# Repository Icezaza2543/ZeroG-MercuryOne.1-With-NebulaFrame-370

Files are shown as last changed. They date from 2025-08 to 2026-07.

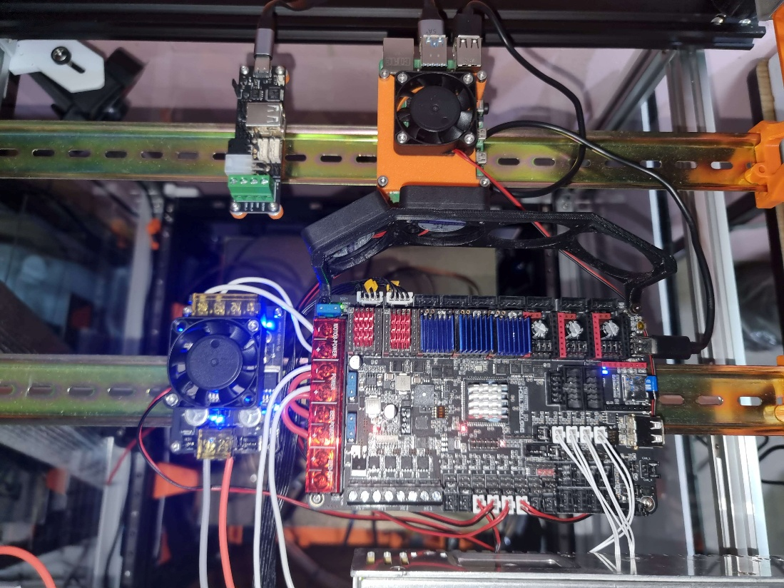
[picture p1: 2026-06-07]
Media/image16.png

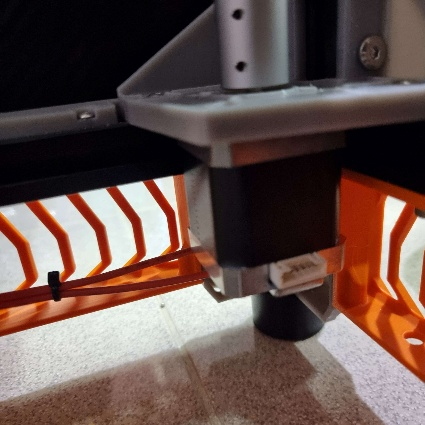
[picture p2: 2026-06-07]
Media/image20.png

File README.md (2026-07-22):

<div align="center">

# 🚀 ZeroG MercuryOne.1 x NebulaFrame 370 x Hydra Bed

### *High-Speed CoreXY 3D Printer Conversion Platform*

**Handmade with ❤️ by Icezaza**








</div>

---

## 📖 1. Project Overview

This project is a comprehensive **CoreXY conversion** platform for **Ender 5 / Ender 5 Pro / Ender 5 Plus** 3D printers. It elevates print speeds beyond **600 mm/s** with accelerations up to **20,000 mm/s²**, designed specifically for reliable high-temperature engineering filament printing (**ABS, ASA, PC**).

### 🔑 Core Pillars

1. **⚡ ZeroG Mercury One.1 (CoreXY Kinematics):**  
   Converts stock single-axis movement into a lightweight, high-acceleration **CoreXY** gantry system for fast, precise motion.
2. **🏗️ NebulaFrame 370 (High-Temp Enclosure):**  
   Sealed acrylic/polycarbonate enclosure frame maintaining ambient chamber temperatures to prevent thermal warping in ABS, ASA, and PC prints.
3. **🔥 Hydra Bed System (3-Point Independent Z-Tilt):**  
   Kinematic **3-Point Z-Tilt** bed mechanism driven by 3 independent Z stepper motors for 100% automated bed tramming and leveling.
4. **🧠 Advanced Klipper Ecosystem:**  
   Powered by a **BigTreeTech Octopus Pro (STM32H723)** controller, **BTT EBB36 CANbus** toolhead MCU, and **Cartographer / Beacon 3D Probe** with pre-configured **KAMP (Klipper Adaptive Meshing & Purging)** and **ShakeTune**.

---

## 📊 2. Technical Specifications

| Specification / Parameter | Details & Hardware Model |
| :--- | :--- |
| **Print Kinematics** | CoreXY Kinematics (ZeroG Mercury One.1) |
| **Max Speed & Acceleration** | **Speed:** >600 mm/s \| **Acceleration:** 20,000 mm/s² |
| **Main Controller** | BigTreeTech Octopus Pro (STM32H723, 32-bit @ 550MHz) |
| **Toolhead MCU** | BigTreeTech EBB36 v1.2 (CANbus Interface) |
| **X/Y Motor Drivers** | 2x TMC5160 Pro (SPI Mode @ 1.97A Run Current) |
| **Z Motor Drivers** | 3x TMC2209 (UART Mode @ 1.45A Run Current) |
| **X/Y Motors** | LDO-42STH48-2804AH-R (High-Torque 0.9° Steppers) |
| **Z Motors** | 3x NEMA17 Steppers (Hydra 3-Point Z-Tilt Drive) |
| **Extruder** | Orbiter 2.0 Dual-Drive Direct Extruder |
| **Bed Surface Scanner** | Cartographer 3D / Beacon 3D Surface Scanner |
| **Part Cooling** | 5015 High-Static Pressure Blower Fan (24V) |
| **Firmware & Software** | Klipper + Moonraker + Mainsail + KAMP + KlipperScreen |

---

## 🏗️ 3. System Architecture & Workflows

```mermaid
graph TD
    A[Ender 5 Platform] -->|Conversion| B(ZeroG Mercury One.1 CoreXY)
    B --> C{Core Components}
    
    C -->|Enclosure| D[NebulaFrame 370 Enclosure]
    C -->|Bed Kinematics| E[Hydra 3-Point Z-Tilt Bed]
    C -->|Toolhead Engine| F[Orbiter 2.0 + EBB36 CANbus]
    C -->|Surface Probe| G[Cartographer / Beacon 3D Probe]

    E -->|Auto Leveling| H[Z_TILT_ADJUST Automated Leveling]
    F & G -->|Control Hub| I[Klipper Firmware + BTT Octopus Pro]
    I -->|Configs| J[Config/printer.cfg]
```

---

## 📂 4. Repository Structure

```mermaid
mindmap
  root((ZeroG-MercuryOne.1))
    BOM.md
      (Hardware Specifications)
    Config
      [printer.cfg & macros.cfg]
      [KAMP & KlipperScreen]
      [crowsnest & timelapse]
    File_To_Print
      (HydraBed STLs)
      (MercuryXY STLs)
      (Skirt STLs)
      (ToolsHead STLs)
    Manuals
      [Assembly_Guide.md]
      [PDF Instructions]
    Archives
      [CAD ZIP Packages]
    Media
      [Build Media & Test Print Video]
```

### 📋 Folder Responsibilities

* 🔩 **[`BOM.md`](BOM.md):** Complete Bill of Materials specifying fasteners, linear rails, belts, motors, and electronics.
* 💾 **[`Config/`](Config/):** Production Klipper configuration files (`printer.cfg`, `macros.cfg`, `KAMP_Settings.cfg`, `KlipperScreen.conf`).
* 🖨️ **[`File_To_Print/`](File_To_Print/):** Categorized 3D printable STL files (`HydraBed/`, `MercuryXY/`, `Skirt/`, `ToolsHead/`).
* 📖 **[`Manuals/`](Manuals/):** Markdown assembly guide ([`Assembly_Guide.md`](Manuals/Assembly_Guide.md)) and official PDF manuals.
* 📦 **[`Archives/`](Archives/):** Compressed archives containing original CAD models.
* 📷 **[`Media/`](Media/):** Video demonstrations and project media assets.

---

## 🛠️ 5. Quick Start & Assembly Guide

### 1️⃣ Step 1: Review Hardware Requirements
Inspect the complete Bill of Materials for screws, heat-set inserts, MGN12H linear rails, and motor specifications in 🔩 **[BOM.md](BOM.md)**.

### 2️⃣ Step 2: Print Required Parts
Slice STL files from 🖨️ **[File_To_Print/](File_To_Print/)** with recommended settings:
* **Recommended Material:** ABS or ASA (High thermal resistance)
* **Wall Loops / Perimeters:** 4–5 walls
* **Top / Bottom Layers:** 5 layers
* **Infill:** 40% (Gyroid or Grid pattern)

### 3️⃣ Step 3: Assemble Mechanical Gantry & Frame
Follow step-by-step assembly instructions in 📖 **[Manuals/Assembly_Guide.md](Manuals/Assembly_Guide.md)**.

### 4️⃣ Step 4: Install Klipper Configuration
Copy configuration files from 💾 **[Config/](Config/)** into your Klipper environment (`printer_data/config/`).

### 5️⃣ Step 5: Execute Machine Calibration
Run Klipper calibration macros via console:

```gcode
# 1. Automatic 3-Point Z-Tilt Leveling
Z_TILT_ADJUST

# 2. Bed Mesh Calibration
BED_MESH_CALIBRATE

# 3. Hotend & Heated Bed PID Tuning
PID_CALIBRATE HEATER=extruder TARGET=240
PID_CALIBRATE HEATER=heater_bed TARGET=100

# 4. Resonance Testing & Input Shaper Calibration
SHAKETUNE
```

---

## ❓ 6. Troubleshooting & FAQs

<details>
<summary><b>❓ Why is ABS or ASA required for printed components?</b></summary>
<br>
Inside the NebulaFrame 370 enclosure, ambient chamber temperatures reach 50–60°C. Parts printed in PLA or PETG will soften and deform under heat, causing gantry misalignment and loose belt tension.
</details>

<details>
<summary><b>❓ What causes Z-Tilt leveling errors or motor binding?</b></summary>
<br>
Verify that motor pin definitions and coordinates for <code>stepper_z</code>, <code>stepper_z1</code>, and <code>stepper_z2</code> in <code>printer.cfg</code> match the physical lead screw positions on your machine.
</details>

<details>
<summary><b>❓ What printing speeds can be reliably achieved?</b></summary>
<br>
While TMC5160 drivers and LDO high-torque steppers support travel speeds over 600 mm/s, high-quality production printing is recommended between 250–450 mm/s for optimal surface finish on ABS/ASA.
</details>

---

## 🤝 7. Credits & Acknowledgements

Special thanks to the open-source community:
* 🚀 **[ZeroG Design Community](https://github.com/ZeroGDesign):** Creators of the ZeroG Mercury One.1 CoreXY platform.
* ⚙️ **[Klipper Project](https://www.klipper3d.org/):** High-performance 3D printer firmware.
* 🇹🇭 **Thai Maker Community (Icezaza):** Design customization and project documentation.

---

<div align="center">

**📄 License:** [CC BY-NC-SA 4.0](https://creativecommons.org/licenses/by-nc-sa/4.0/) & [CC0 1.0 Universal](LICENSE)  

*⭐ If you find this project helpful, please give it a star on GitHub!*

</div>

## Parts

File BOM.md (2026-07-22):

# 🔩 Bill of Materials (BOM) - ZeroG MercuryOne.1 x NebulaFrame 370 x Hydra Bed

**Project:** ZeroG Mercury One.1 CoreXY Conversion + NebulaFrame 370 + Hydra Bed  
**Author:** Thai Maker (Icezaza)  
**Target Printer Platform:** Ender 5 / Ender 5 Pro / Ender 5 Plus  

---

## 📑 1. Core Electronics & Hardware Specs

| Category | Component | Specification / Model | Qty | Notes |
| :--- | :--- | :--- | :---: | :--- |
| **Main Controller** | Mainboard | BigTreeTech Octopus Pro (STM32H723) | 1 | 32-bit controller, high-speed USB/CAN |
| **Toolhead MCU** | Toolhead CAN Board | BTT EBB36 v1.1 / v1.2 (CANbus) | 1 | Mounts directly on Orbiter 2.0 |
| **Host System** | Single Board Computer | Raspberry Pi 3/4 / CB1 | 1 | Runs Klipper, Mainsail, Moonraker |
| **X/Y Steppers** | High-Speed Motors | LDO-42STH48-2804AH-R (2.8A, 0.9°) | 2 | CoreXY Motion (Driven by TMC5160 @ 1.97A) |
| **Z Steppers** | Hydra Bed Motors | NEMA17 (42DND887C-20D18 1.7A) | 3 | 3-Point Independent Z-Tilt Kinematic Bed |
| **X/Y Drivers** | Stepper Drivers | BTT TMC5160 Pro / TMC5160 (SPI) | 2 | High current & high speed motion |
| **Z Drivers** | Stepper Drivers | BTT TMC2209 (UART) | 3 | Quiet operation with stealthChop/spreadCycle |
| **Toolhead Extruder**| Extruder | Orbiter 2.0 Dual Drive | 1 | Lightweight direct-drive extruder |
| **Surface Probe** | 3D Bed Scanner | Cartographer 3D / Beacon 3D Probe | 1 | High-speed Eddy Current Surface Scanner |
| **Part Cooling** | Blower Fan | 5015 Dual Ball Bearing Fan (24V) | 1 | Single/Dual 5015 Duct Mount |
| **Hotend Fan** | Cooling Fan | 3010 Axial Fan (24V) | 1 | EBB36 Toolhead Cooling |
| **Resonance Test** | Accelerometer | ADXL345 (Integrated on EBB36) | 1 | Input Shaper Calibration |

---

## 🏗️ 2. Mechanical & Linear Motion (Kinematics)

| Component | Specification | Qty | Notes |
| :--- | :--- | :---: | :--- |
| **Linear Rails (X-Axis)** | MGN12H (300mm / 350mm / 450mm based on Ender model) | 1 | Heavy-duty top-rail carriage mount |
| **Linear Rails (Y-Axis)** | MGN12H | 2 | Side rail positioning |
| **Linear Rails (Z-Axis)** | MGN12H | 3 | Hydra 3-point vertical guides |
| **GT2 Belt (X/Y)** | GT2 6mm or 9mm Gates Unitta Belt | ~4.5m | CoreXY belt loop routing |
| **Pulleys (Toothed)** | 20T GT2 Pulley (5mm bore) | 2 | X/Y Stepper Motor Shafts |
| **Idlers (Smooth)** | 20T Smooth Idler (5mm bore) | 6 | Gantry corner & tensioners |
| **Idlers (Toothed)** | 20T Toothed Idler (5mm bore) | 8 | Gantry corner & tensioners |
| **Lead Screws** | T8x4 / T8x8 Lead Screw + Anti-backlash Nut | 3 | Hydra Z-Axis motor drives |

---

## 🔩 3. Fasteners & Brass Inserts (Hardware BOM)

| Fastener Type | Dimensions | Approximate Qty | Application |
| :--- | :--- | :---: | :--- |
| **Heat-Set Inserts** | M3 x 5mm x 4mm (Brass) | 60+ | All 3D Printed Parts |
| **Button Head Screws**| M3 x 6mm | 40+ | Rail mounting & brackets |
| **Button Head Screws**| M3 x 8mm | 50+ | Frame & component mounts |
| **Button Head Screws**| M3 x 12mm | 30+ | Motor mounts & joints |
| **Button Head Screws**| M3 x 16mm / 20mm | 20+ | Toolhead & fan mounts |
| **Socket Head Screws**| M4 x 10mm / 12mm | 20+ | Frame extrusions |
| **Socket Head Screws**| M5 x 10mm / 16mm | 16+ | Corner brackets & bed mounts |
| **T-Nuts** | M3 T-Nuts for 2020 Aluminum Profile | 50+ | Rail & skirt mounting |
| **T-Nuts** | M4 / M5 T-Nuts for 2020 Profile | 30+ | Heavy joint mounting |

---

## 🖼️ 4. Frame & Enclosure (NebulaFrame 370)

| Material | Description / Dimensions | Qty | Application |
| :--- | :--- | :---: | :--- |
| **Aluminum Extrusions** | 2020 T-Slot Aluminum Profile | Cut to spec | Upper frame expansion & enclosure |
| **Enclosure Panels** | Acrylic or Polycarbonate Panels (3mm - 4mm) | 5 Sheets | Top, Sides, Front Doors for ABS/PC printing |
| **Insulation / Skirt** | 3D Printed Skirts (`File_To_Print/Skirt`) | 1 Set | Bottom enclosure & electronics housing |

---

## 🖨️ 5. Recommended 3D Printing Settings for Parts

| Parameter | Value |
| :--- | :--- |
| **Material** | **ABS** or **ASA** (Polycarbonate optional for high ambient temp) |
| **Wall Loops / Perimeters** | Minimum **4 Walls** (5 recommended for stress joints) |
| **Top / Bottom Layers** | **5 Solid Layers** |
| **Infill Density** | **40%** |
| **Infill Pattern** | Gyroid, Grid, or Honeycomb |
| **Layer Height** | 0.2mm |

---

<div align="center">
  <b>For Klipper Configuration files, please refer to the <a href="Config/">Config/</a> directory.</b>
</div>

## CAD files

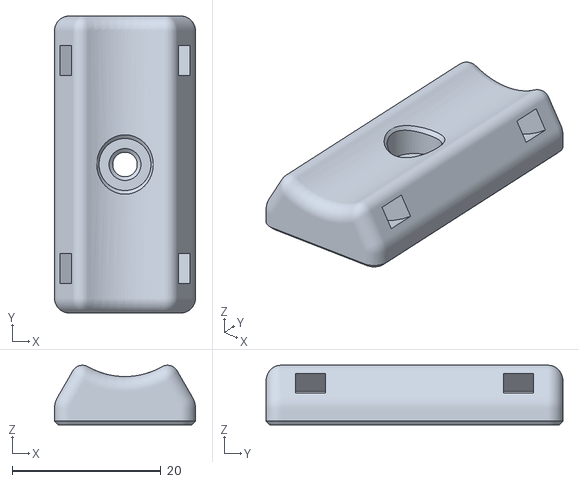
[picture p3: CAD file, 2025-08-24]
File_To_Print/HydraBed/2020_CableTie.stl
19.0 x 40.0 x 8.03

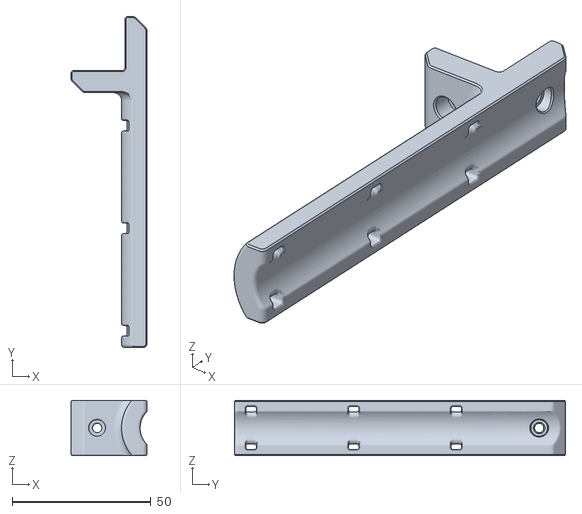
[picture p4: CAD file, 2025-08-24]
File_To_Print/MercuryXY/RearSplitloomArm_V1-1-0.stl
27.5 x 119.5 x 20.0

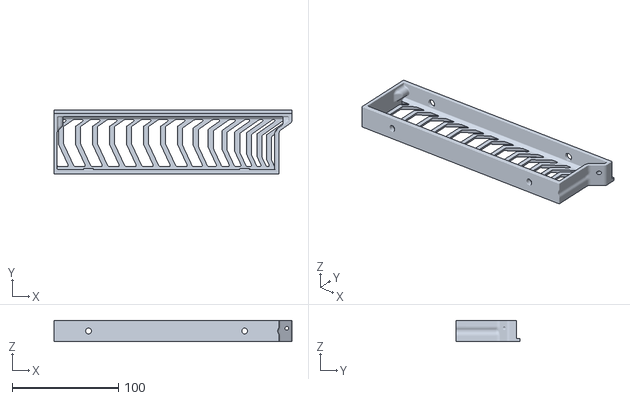
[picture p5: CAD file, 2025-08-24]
File_To_Print/Skirt/SK_480L.stl
224.1 x 60.0 x 20.0

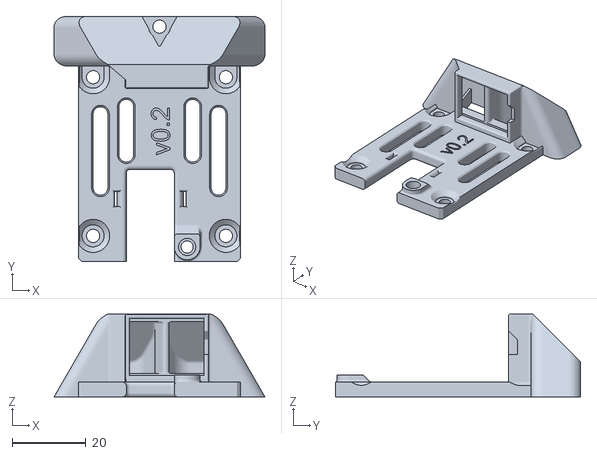
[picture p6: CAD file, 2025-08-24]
File_To_Print/ToolsHead/rear_inlet_single_5015.stl
57.2 x 66.5 x 22.5

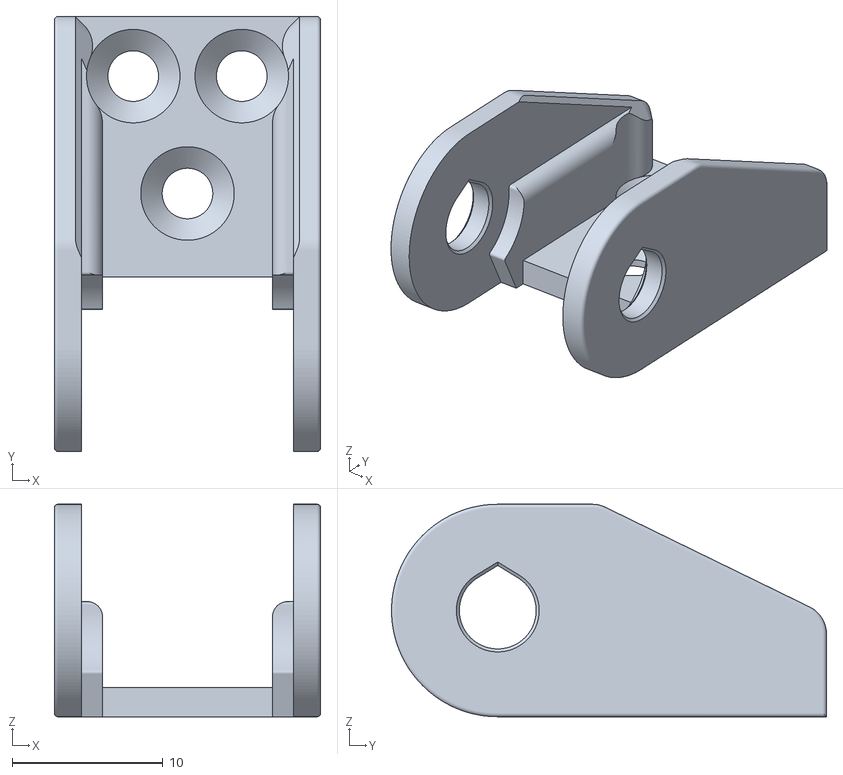
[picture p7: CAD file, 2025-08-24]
File_To_Print/HydraBed/ChainEnd.stl
17.7 x 28.9 x 14.1

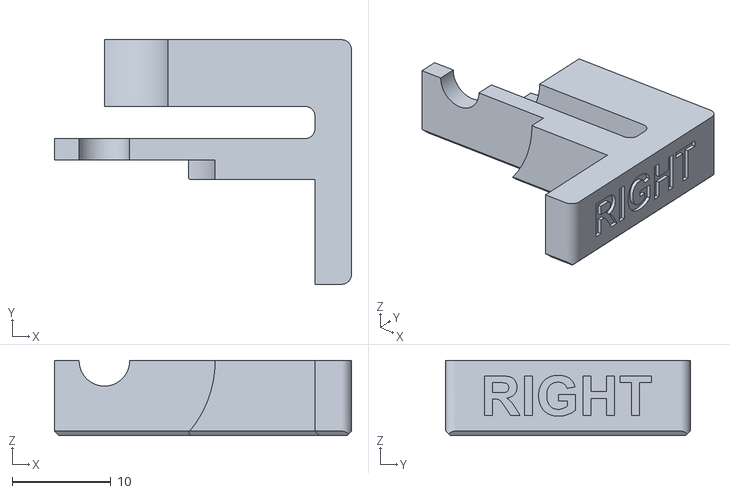
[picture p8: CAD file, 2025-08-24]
File_To_Print/MercuryXY/right_pulley_alignment_tool.stl
30.0 x 24.8 x 7.60

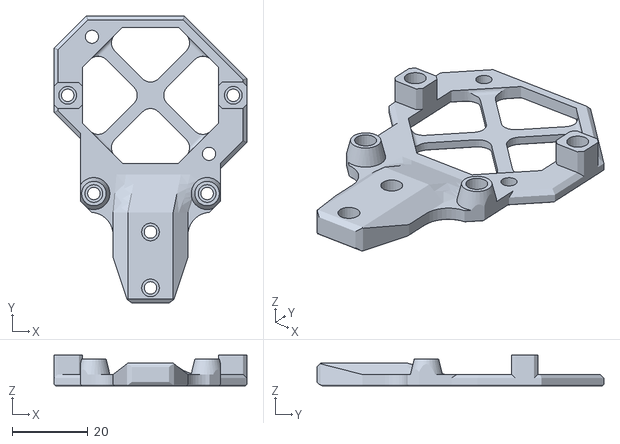
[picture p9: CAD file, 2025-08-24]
File_To_Print/ToolsHead/pcb36_mount.stl
51.0 x 76.0 x 8.10

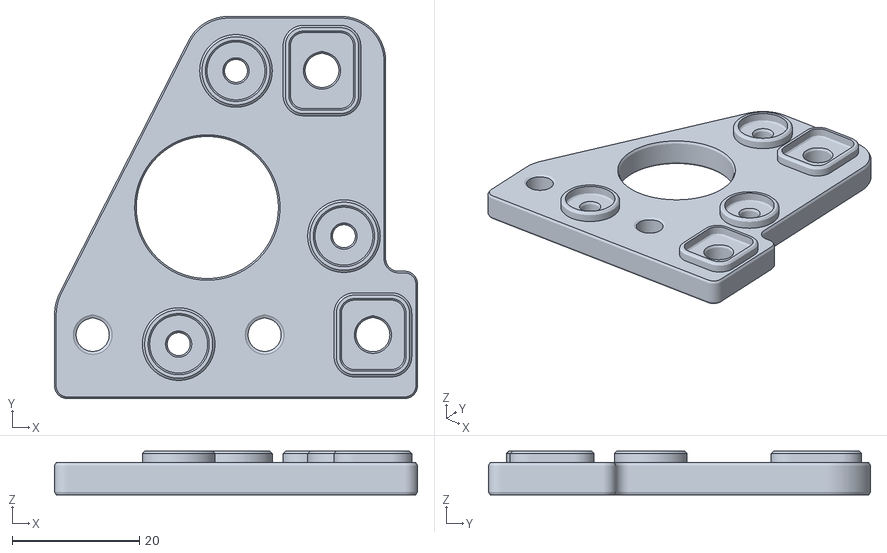
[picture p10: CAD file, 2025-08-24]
File_To_Print/MercuryXY/a_stepper_mount_top_right.stl
57.0 x 60.0 x 6.85

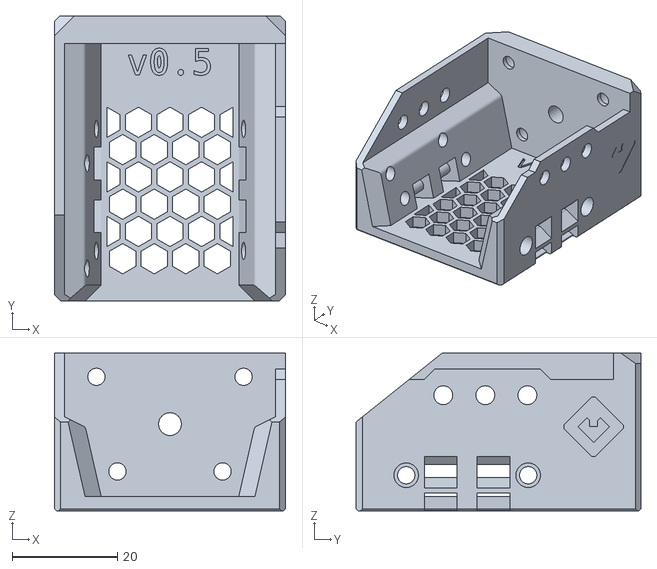
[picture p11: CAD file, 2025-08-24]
File_To_Print/ToolsHead/front_basic.stl
44.0 x 54.2 x 30.0

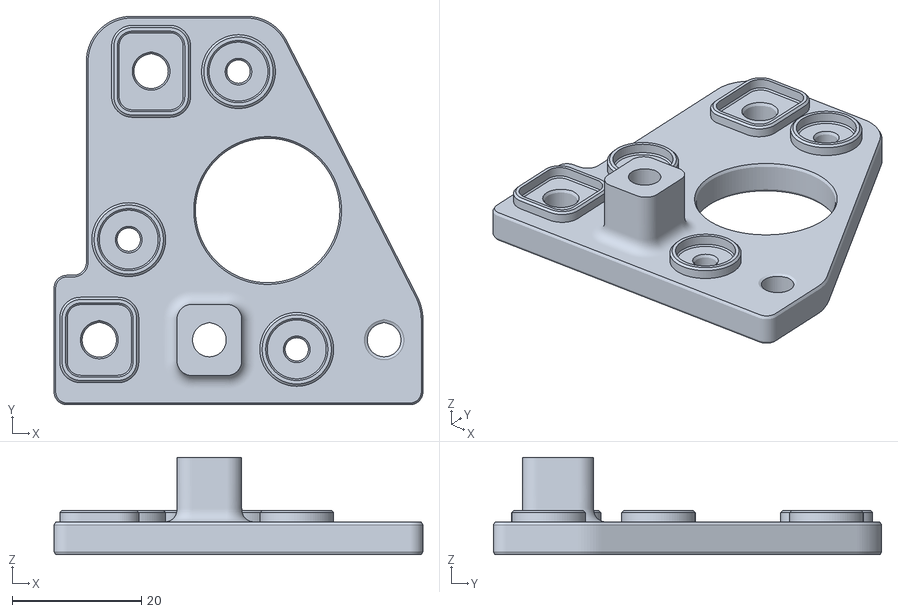
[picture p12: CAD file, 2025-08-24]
File_To_Print/MercuryXY/a_stepper_mount_top_left.stl
57.0 x 60.0 x 15.0

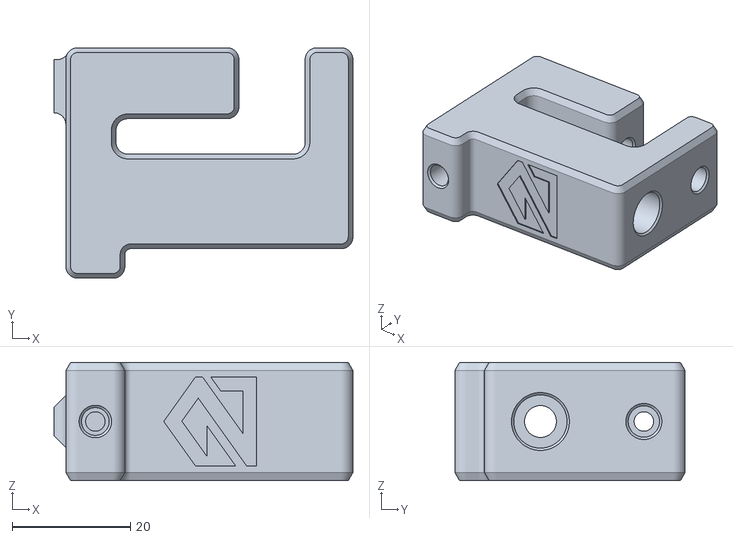
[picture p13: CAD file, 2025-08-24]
File_To_Print/MercuryXY/a_front_tower_right.stl
50.6 x 39.0 x 20.0

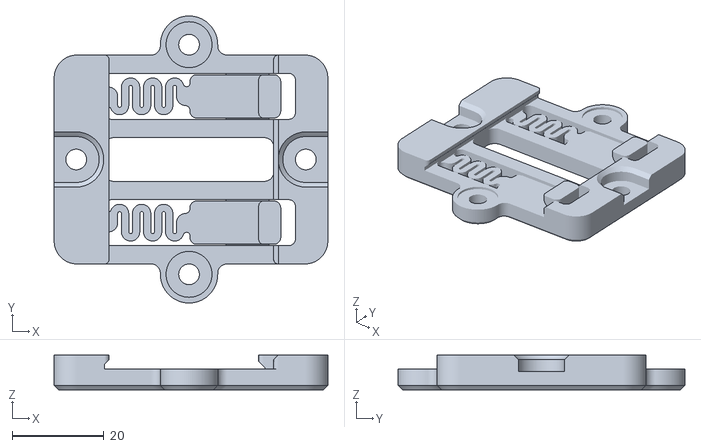
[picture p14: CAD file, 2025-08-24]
File_To_Print/ToolsHead/50mm_din_rail_mount.stl
59.6 x 62.5 x 7.60

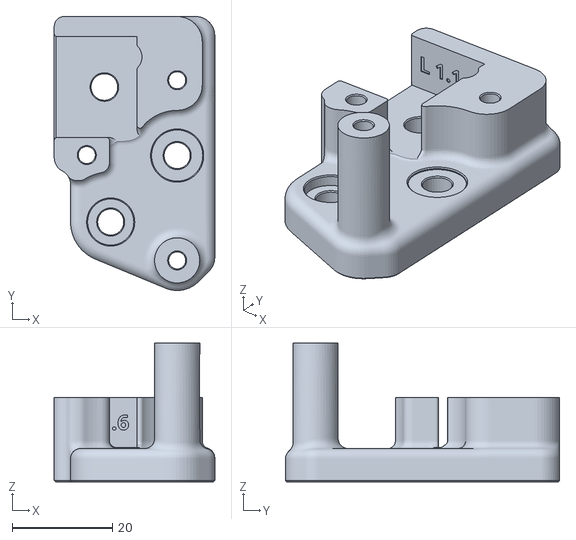
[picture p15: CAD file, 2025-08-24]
File_To_Print/MercuryXY/XJoint_left_top.stl
32.0 x 54.6 x 27.6

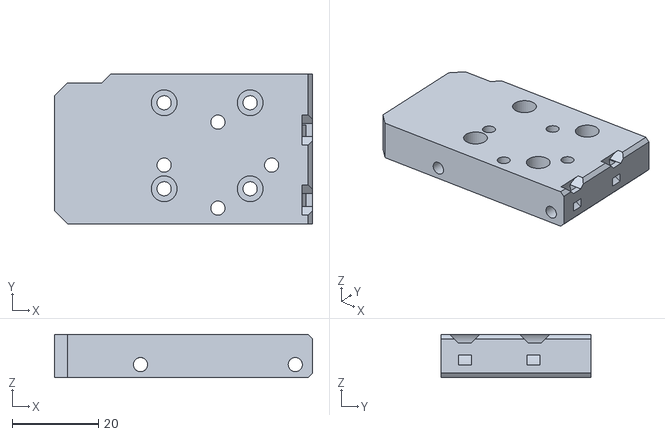
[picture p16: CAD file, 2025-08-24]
File_To_Print/ToolsHead/E34M1_Top_Limit_Right.stl
60.0 x 34.8 x 10.0

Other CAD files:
File_To_Print/Skirt/SK_480R.stl
File_To_Print/MercuryXY/plus_only_bed_raiser_1.stl
File_To_Print/ToolsHead/drive_orbiter_2_0.stl
File_To_Print/MercuryXY/XJoint_left_bottom.stl
File_To_Print/MercuryXY/XJoint_right_bottom.stl
File_To_Print/MercuryXY/XJoint_right_top.stl
File_To_Print/MercuryXY/a_FlangeSpacer_pair.stl
File_To_Print/MercuryXY/a_Xjoint_8mm_Idler_Spacers.stl
File_To_Print/MercuryXY/a_front_tower_left.stl
File_To_Print/MercuryXY/a_stepper_mount_bottom_left.stl
File_To_Print/MercuryXY/a_stepper_mount_bottom_right.stl
File_To_Print/MercuryXY/front_tension_plate_t-nut_1.stl
File_To_Print/MercuryXY/front_tension_plate_t-nut_2.stl
File_To_Print/MercuryXY/front_tower_tool.stl
File_To_Print/MercuryXY/front_tower_tool_brass.stl
File_To_Print/MercuryXY/left_pulley_alignment_tool.stl
File_To_Print/MercuryXY/plus_only_bed_raiser_2.stl
File_To_Print/MercuryXY/plus_only_bed_raiser_3.stl
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

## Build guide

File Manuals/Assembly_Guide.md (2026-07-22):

# 📘 ZeroG MercuryOne.1 + NebulaFrame 370 + Hydra Bed Assembly Guide

**Last Updated:** 2026  
**Author:** Thai Maker (Icezaza)  

This guide provides technical overview, system architecture, and assembly procedures for converting an Ender 5 series 3D printer into a high-speed CoreXY system using the ZeroG Mercury One.1 platform, NebulaFrame 370 enclosure, and Hydra 3-point kinematic Z-tilt bed leveling.

---

## 🏗️ 1. Project Overview

This project converts Ender 5 / Ender 5 Pro / Ender 5 Plus printers into high-speed CoreXY machines capable of print speeds exceeding **600 mm/s** and accelerations up to **20,000 mm/s²**, optimized for high-temperature engineering filaments like **ABS, ASA, and PC**.

**Key Core Pillars:**
1. **ZeroG Mercury One.1:** CoreXY motion system replacing single-axis X/Y movement, reducing toolhead weight for fast, precise motion.
2. **NebulaFrame 370:** Sealed enclosure frame maintaining ambient chamber temperatures to eliminate warping in high-shrinkage plastics (ABS/ASA/PC).
3. **Hydra Bed System:** 3-point kinematic Z-tilt mechanism driven by 3 independent Z stepper motors for 100% automated bed leveling.
4. **Klipper Firmware Ecosystem:** Advanced motion processing featuring Input Shaper resonance compensation, Pressure Advance, KAMP adaptive meshing, and ShakeTune diagnostics.

---

## 📂 2. Repository Structure

- **`BOM.md`**
  - Detailed Bill of Materials specifying hardware, fasteners, linear rails, belts, motors, and controller pinouts ([View BOM](../BOM.md)).
- **`Config/`**
  - Production Klipper configuration files including `printer.cfg`, `macros.cfg`, `KAMP_Settings.cfg`, `KlipperScreen.conf`, and `crowsnest.conf` ([Open Config Directory](../Config/)).
- **`Archives/`**
  - Compressed `.zip` archives containing original CAD models (`Hydra_5Plus.zip`, `Hydra_5pro.zip`, `Mercury1_1.zip`).
- **`File_To_Print/`**
  - Categorized 3D printable STL files:
    - `HydraBed/` - 3-motor Z-bed mounts & kinematic arms
    - `MercuryXY/` - CoreXY gantry, belt paths, and motor mounts
    - `Skirt/` - Electronics enclosures and lower frame skirts
    - `ToolsHead/` - Orbiter 2.0, Cartographer/Beacon 3D probe mounts, and 5015 fan ducts
- **`Manuals/`**
  - Official PDF instruction manuals and this markdown assembly guide.
- **`Media/`**
  - Test print videos (`Print_Test.mp4`) and build photography.

---

## 🛠️ 3. Pre-Assembly Guidelines

### 3D Printing Recommendations
All components in `File_To_Print/` are load-bearing structural parts operating in a heated chamber environment:
- **Recommended Materials:** ABS, ASA, or PC (PLA and PETG are not recommended due to heat deflection).
- **Perimeters / Walls:** Minimum **4 walls** (5 walls recommended for high-stress joints).
- **Infill Density:** **40%** (Gyroid, Grid, or Honeycomb).
- **Top / Bottom Solid Layers:** **5 layers**.

### Hardware Bill of Materials (BOM)
For exact quantities of M3/M4/M5 screws, brass heat-set inserts, linear rails, belts, and motor models, refer to 📖 **[BOM.md](../BOM.md)**.

---

## ⚙️ 4. Mechanical Assembly & Klipper Configuration

### 4.1 Part Preparation
1. Print all required parts from `File_To_Print/` according to the recommended print settings.
2. Install brass heat-set inserts (M3x5x4mm) into specified mounting holes using a soldering iron.
3. Cut 2020 aluminum extrusions and prepare acrylic/polycarbonate panels according to NebulaFrame 370 dimensions.

### 4.2 Mechanical Assembly
Follow the instructions in `mercury_one_1_instruction_18-02-2024.pdf` located in the `Manuals/` directory:
1. **CoreXY Gantry Installation:** Mount X and Y stepper motors to the frame and route GT2 belts in the CoreXY configuration.
2. **Hydra Bed Assembly:** Convert the stock bed platform to a 3-lead-screw kinematic mount driven by 3 independent Z steppers.
3. **Toolhead Assembly:** Assemble the Orbiter 2.0 extruder, BTT EBB36 CAN board, and probe onto the X-carriage.

### 4.3 Klipper Firmware Setup
1. Install Klipper on your host single-board computer (Raspberry Pi / CB1 running MainsailOS or FluiddPI).
2. Flash Klipper firmware to the main controller board (e.g., BigTreeTech Octopus Pro) and Toolhead MCU (EBB36).
3. Copy all files from the **[`Config/`](../Config/)** directory to your Klipper `printer_data/config/` folder:
   - **[`Config/printer.cfg`](../Config/printer.cfg)**: Configures TMC5160 X/Y drivers, TMC2209 Z steppers, Cartographer/Beacon probe, and bed mesh settings.
   - **[`Config/macros.cfg`](../Config/macros.cfg)**: Contains `PRINT_START`, `PRINT_END`, `CANCEL_PRINT`, and maintenance macros.

### 4.4 Machine Calibration
Execute calibration macros via the Klipper console:
- **Z-Tilt Leveling:** Run `Z_TILT_ADJUST` to automatically level the bed across all 3 Z steppers.
- **Bed Mesh:** Run `BED_MESH_CALIBRATE` (or rely on KAMP auto-mesh during `PRINT_START`).
- **Resonance Compensation:** Run `SHAKETUNE` or Input Shaper calibration using the ADXL345 accelerometer.
- **PID Tuning:** Run PID calibration for both hotend and heated bed (`PID_CALIBRATE`).

---

## 📌 5. Troubleshooting

- **Belt Friction / Binding:** Ensure smooth alignment of all 20T idlers and equal belt tension across A/B loops.
- **Z-Tilt Failures / Motor Binding:** Verify motor stepper assignments (`stepper_z`, `stepper_z1`, `stepper_z2`) and pivot point coordinates in `printer.cfg`.
- **Layer Shifting at High Speeds:** Check TMC5160 run currents (recommended 1.97A for LDO 0.9° steppers) and verify belt tensioning.

---

**⭐ For additional model modifications, CAD files are available in the `Archives/` folder.**

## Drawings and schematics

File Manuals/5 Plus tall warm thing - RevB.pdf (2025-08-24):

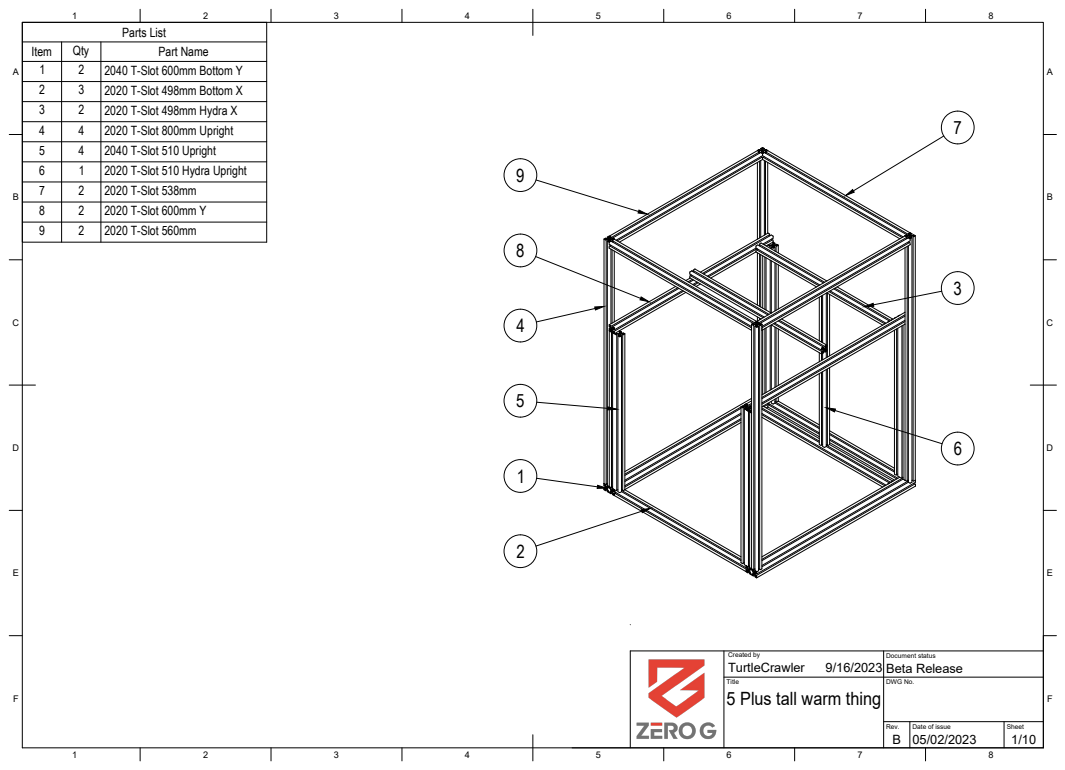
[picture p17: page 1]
Parts List

Item | Qty | Part Name
1 | 2 | 2040 T-Slot 600mm Bottom Y
2 | 3 | 2020 T-Slot 498mm Bottom X
3 | 2 | 2020 T-Slot 498mm Hydra X
4 | 4 | 2020 T-Slot 800mm Upright
5 | 4 | 2040 T-Slot 510 Upright
6 | 1 | 2020 T-Slot 510 Hydra Upright
7 | 2 | 2020 T-Slot 538mm
8 | 2 | 2020 T-Slot 600mm Y
9 | 2 | 2020 T-Slot 560mm

Created by TurtleCrawler 9/16/2023 | Document status Beta Release

Title 5 Plus tall warm thing | DWG No.

Rev. B | Date of issue 05/02/2023 | Sheet

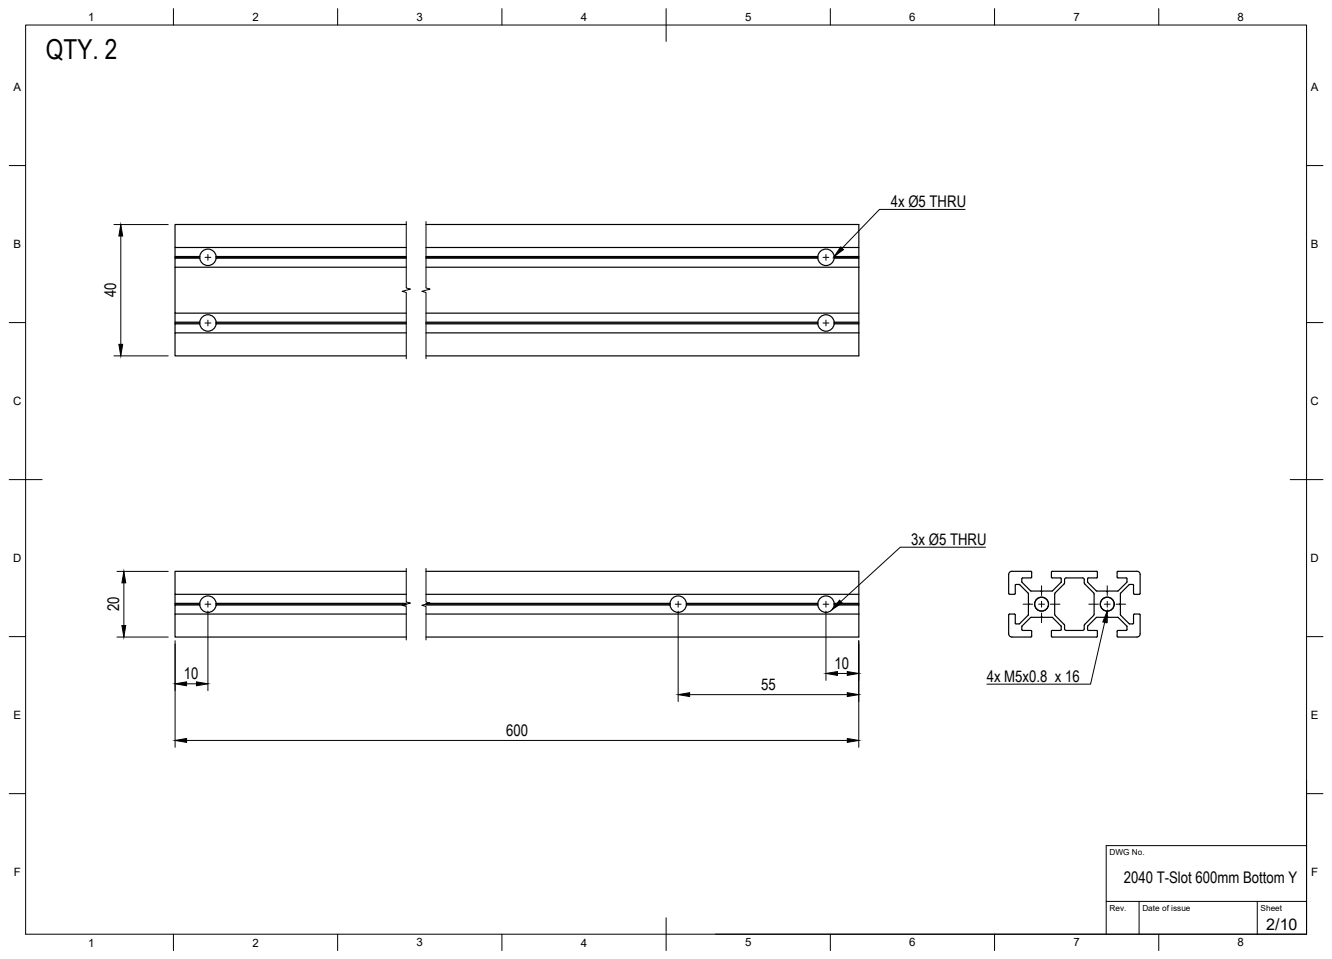
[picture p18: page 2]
DWG No. 2040 T-Slot 600mm Bottom Y; QTY. 2; 4x Ø5 THRU; 3x Ø5 THRU

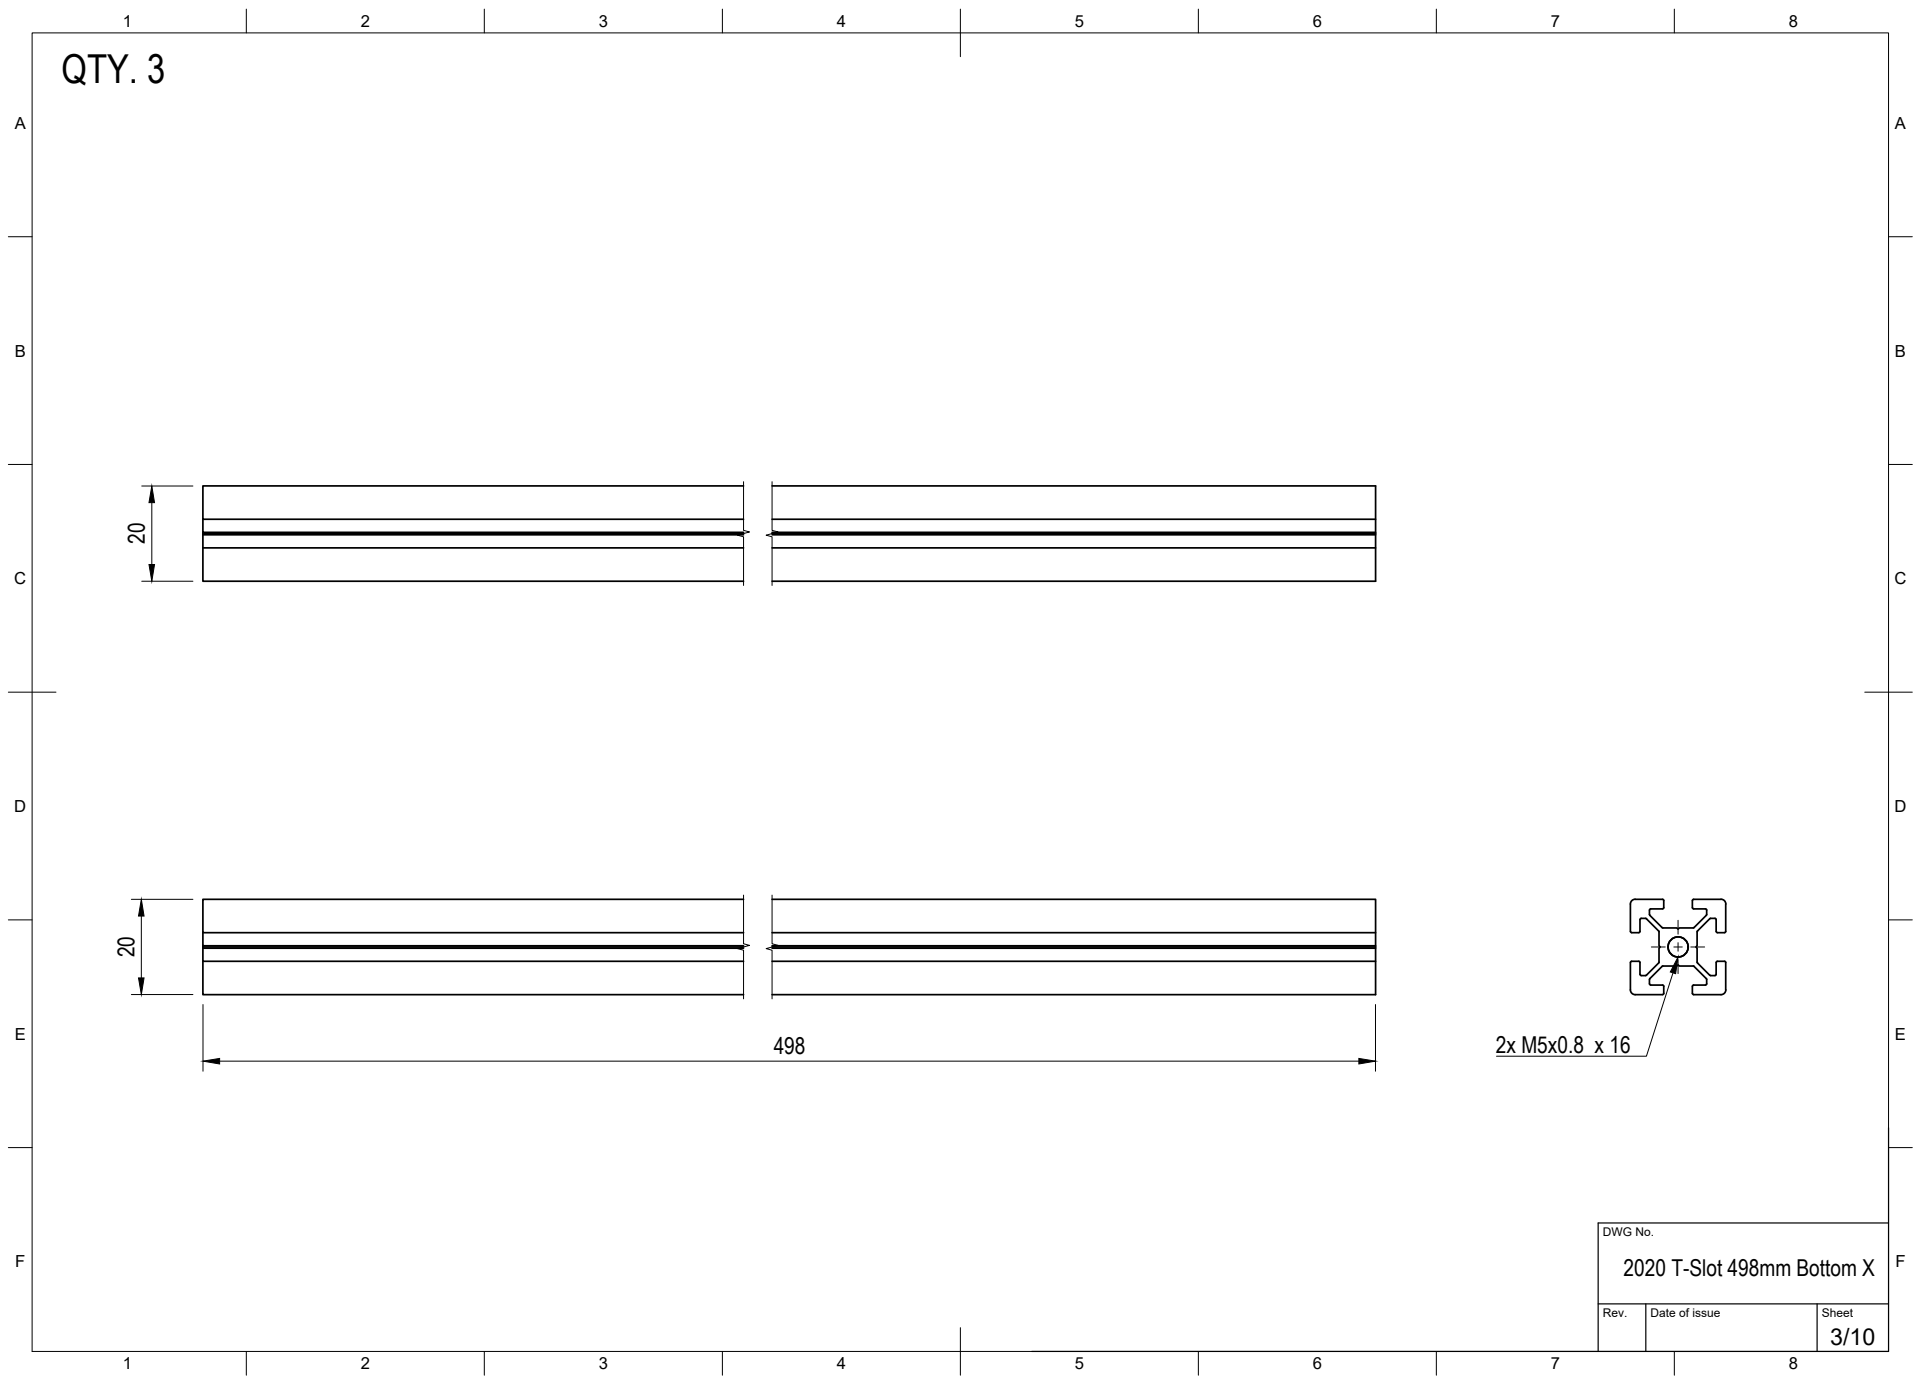
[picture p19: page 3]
DWG No. 2020 T-Slot 498mm Bottom X

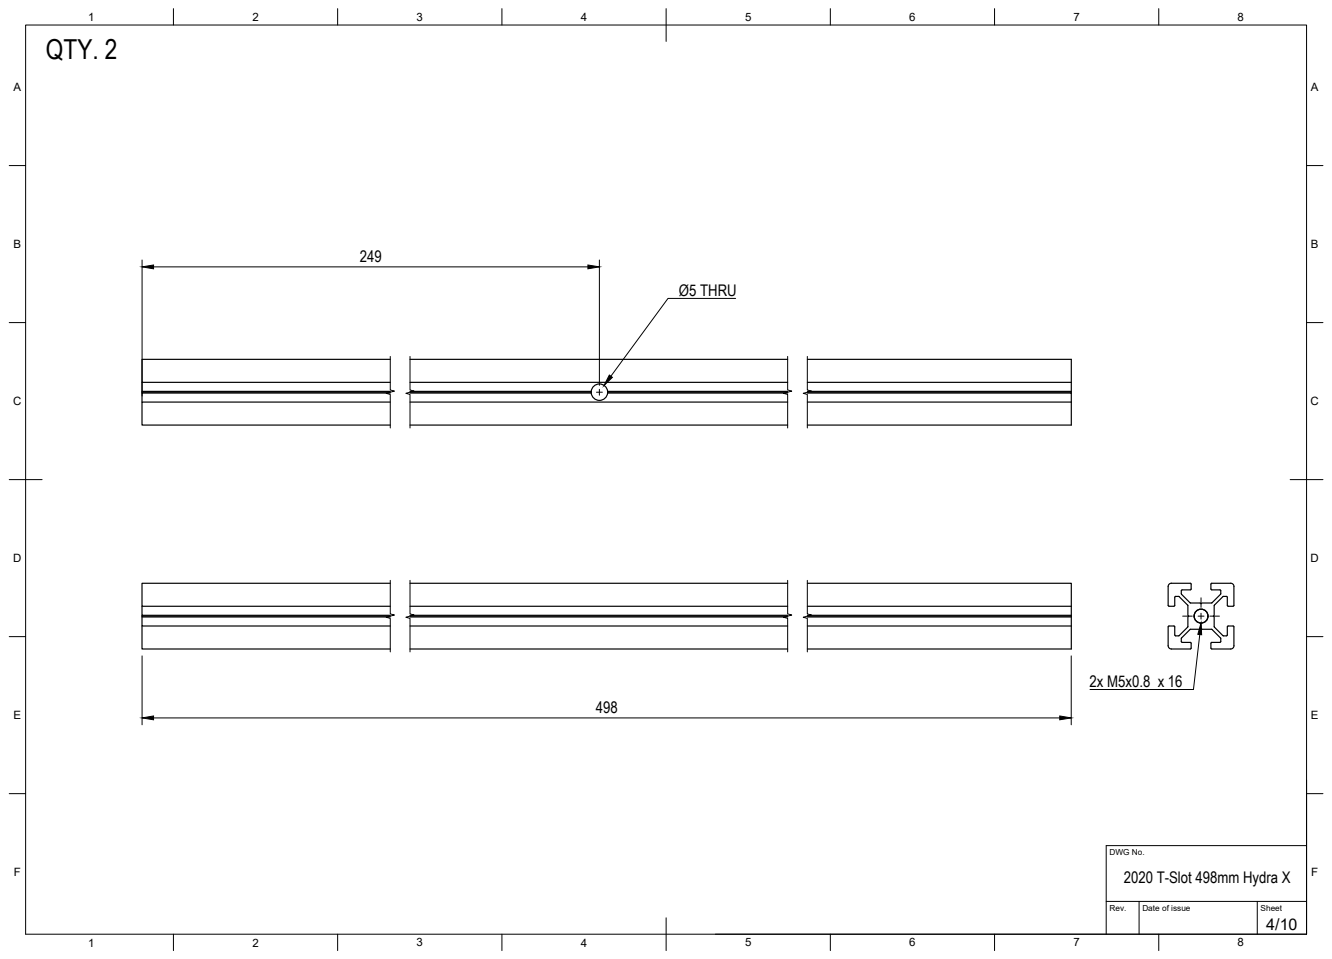
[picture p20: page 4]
DWG No. 2020 T-Slot 498mm Hydra X; Ø5 THRU

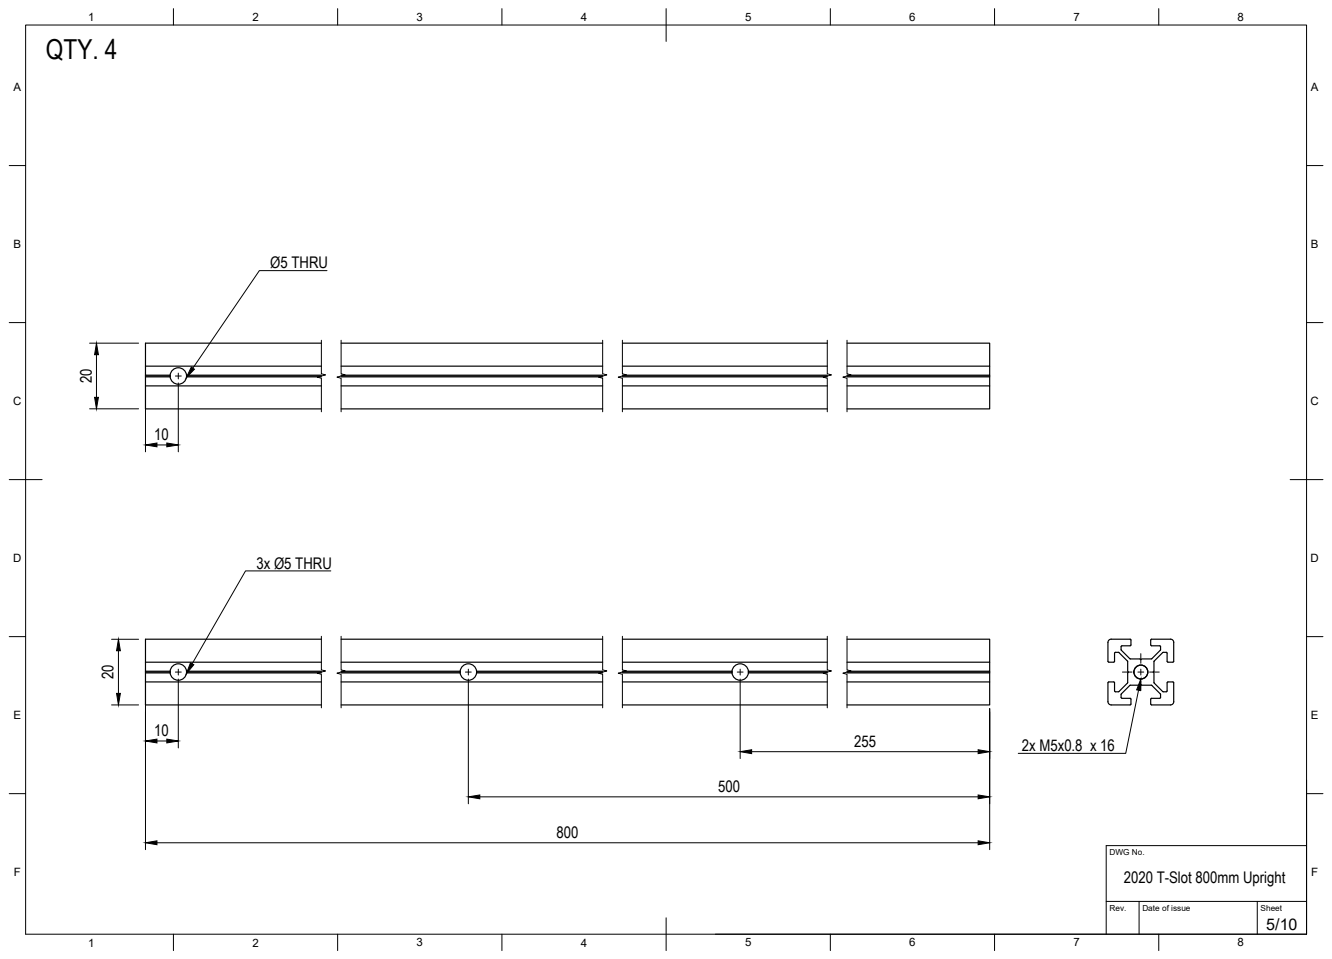
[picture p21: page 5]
DWG No. 2020 T-Slot 800mm Upright; Ø5 THRU; 3x Ø5 THRU

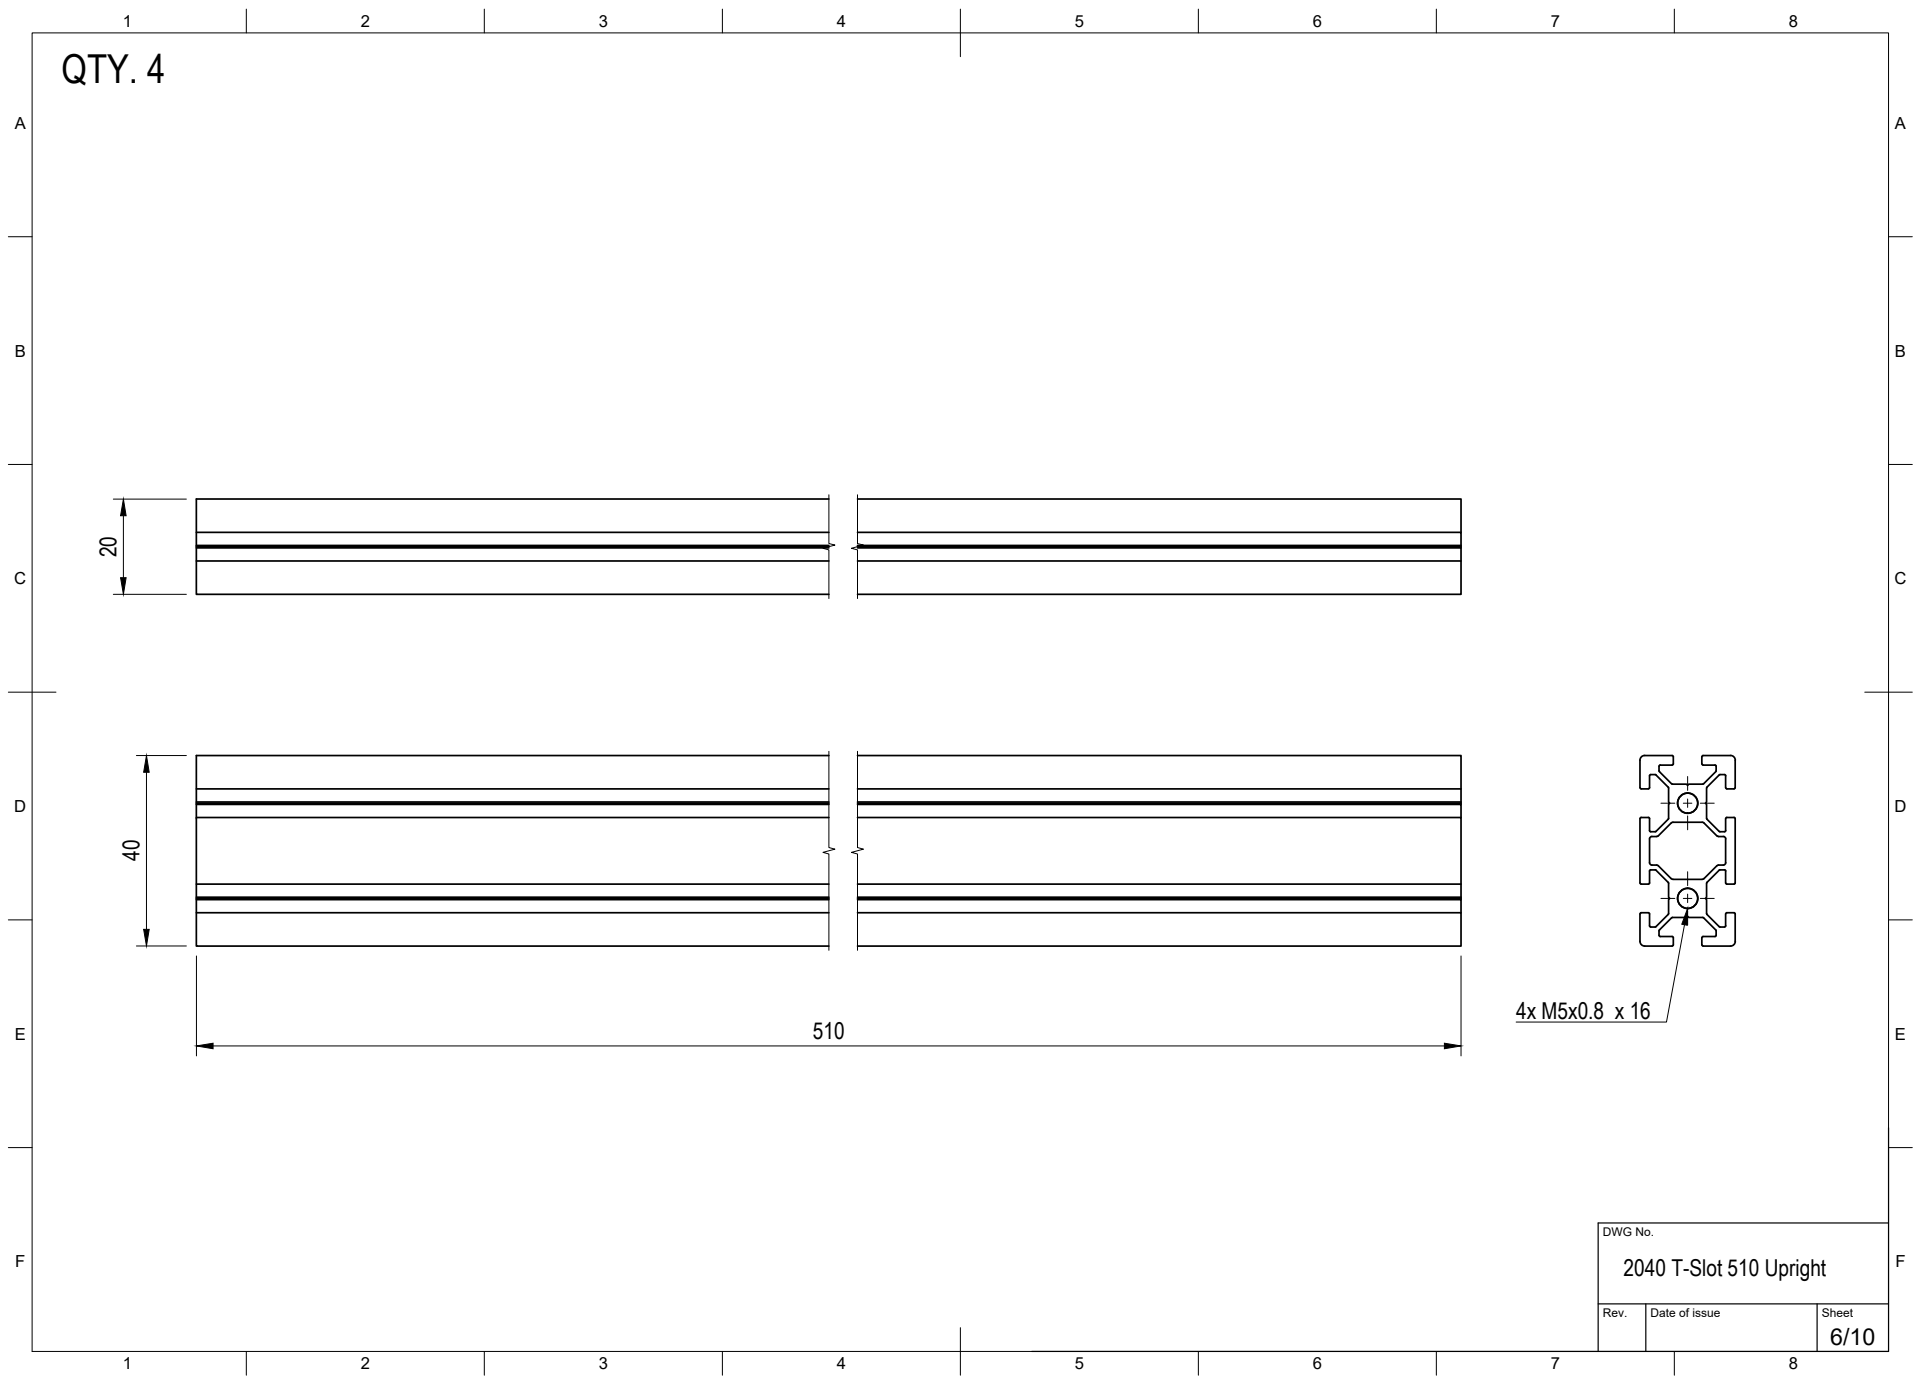
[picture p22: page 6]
DWG No. 2040 T-Slot 510 Upright

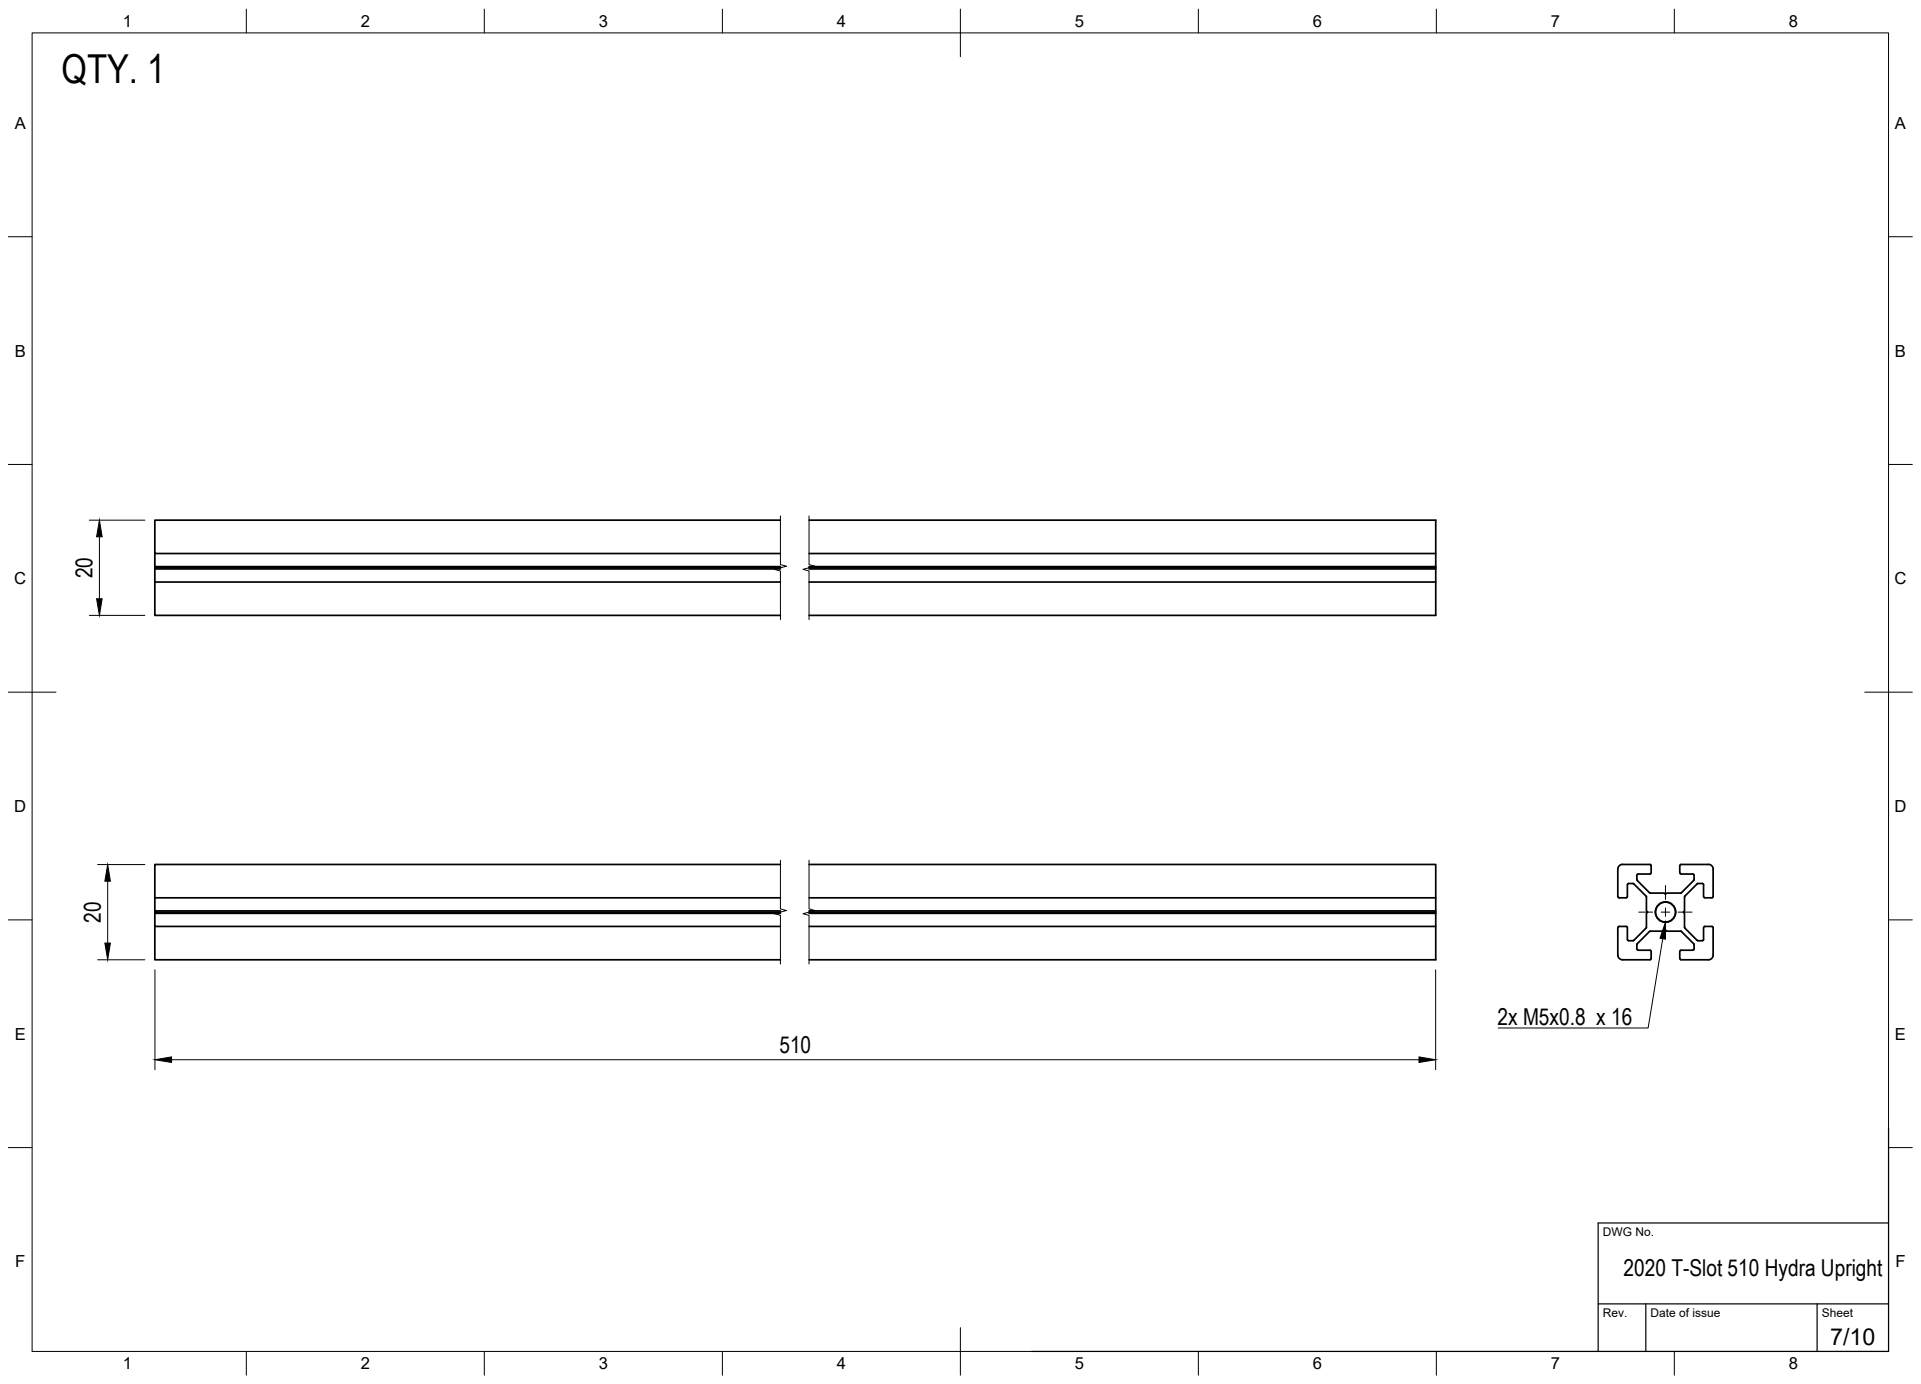
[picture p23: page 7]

DWG No.
2020 T-Slot 510 Hydra Upright

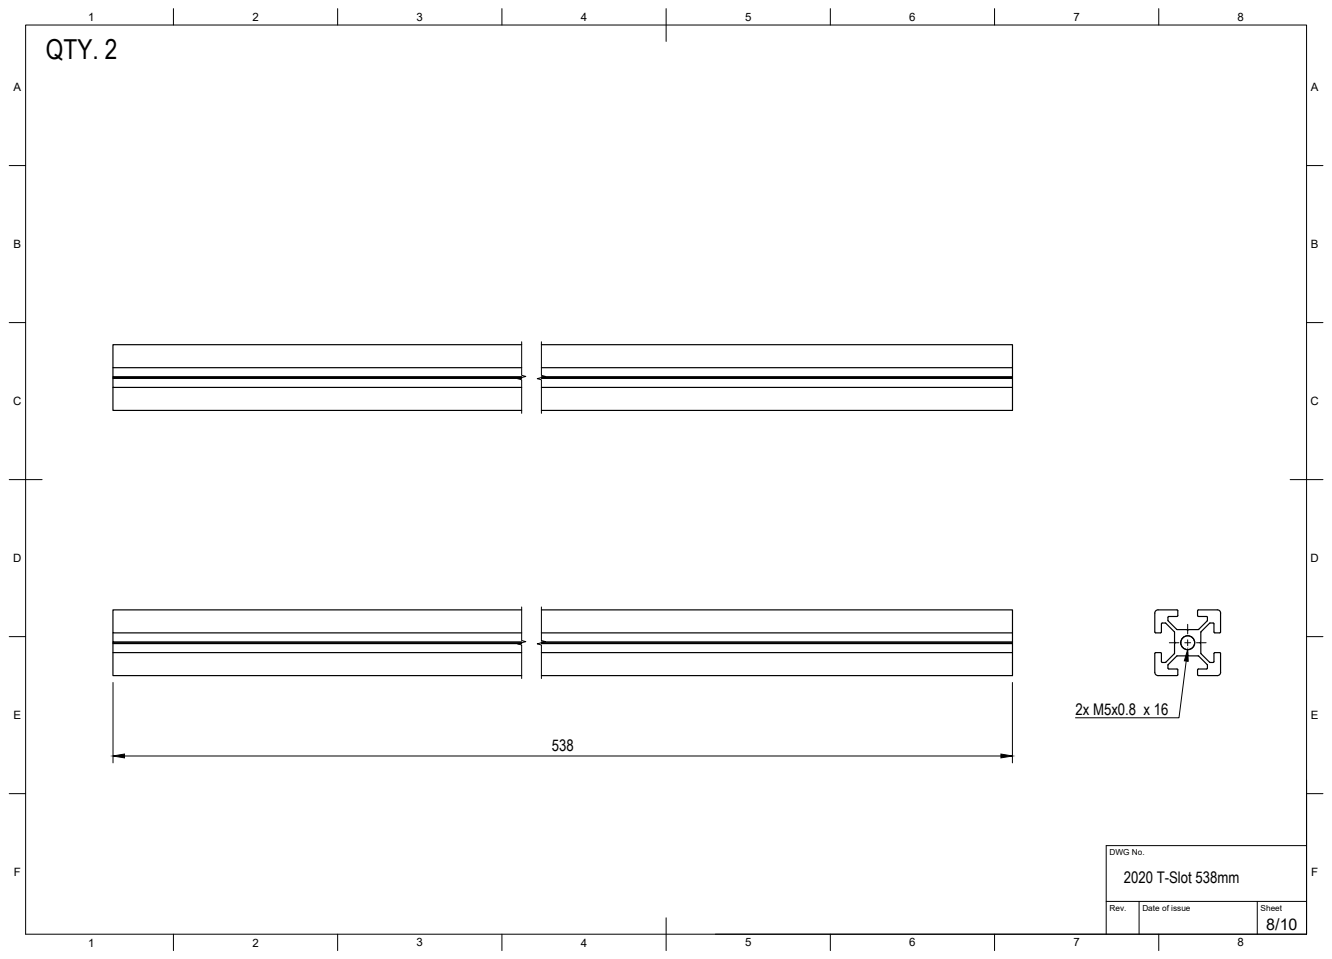
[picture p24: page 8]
DWG No. 2020 T-Slot 538mm

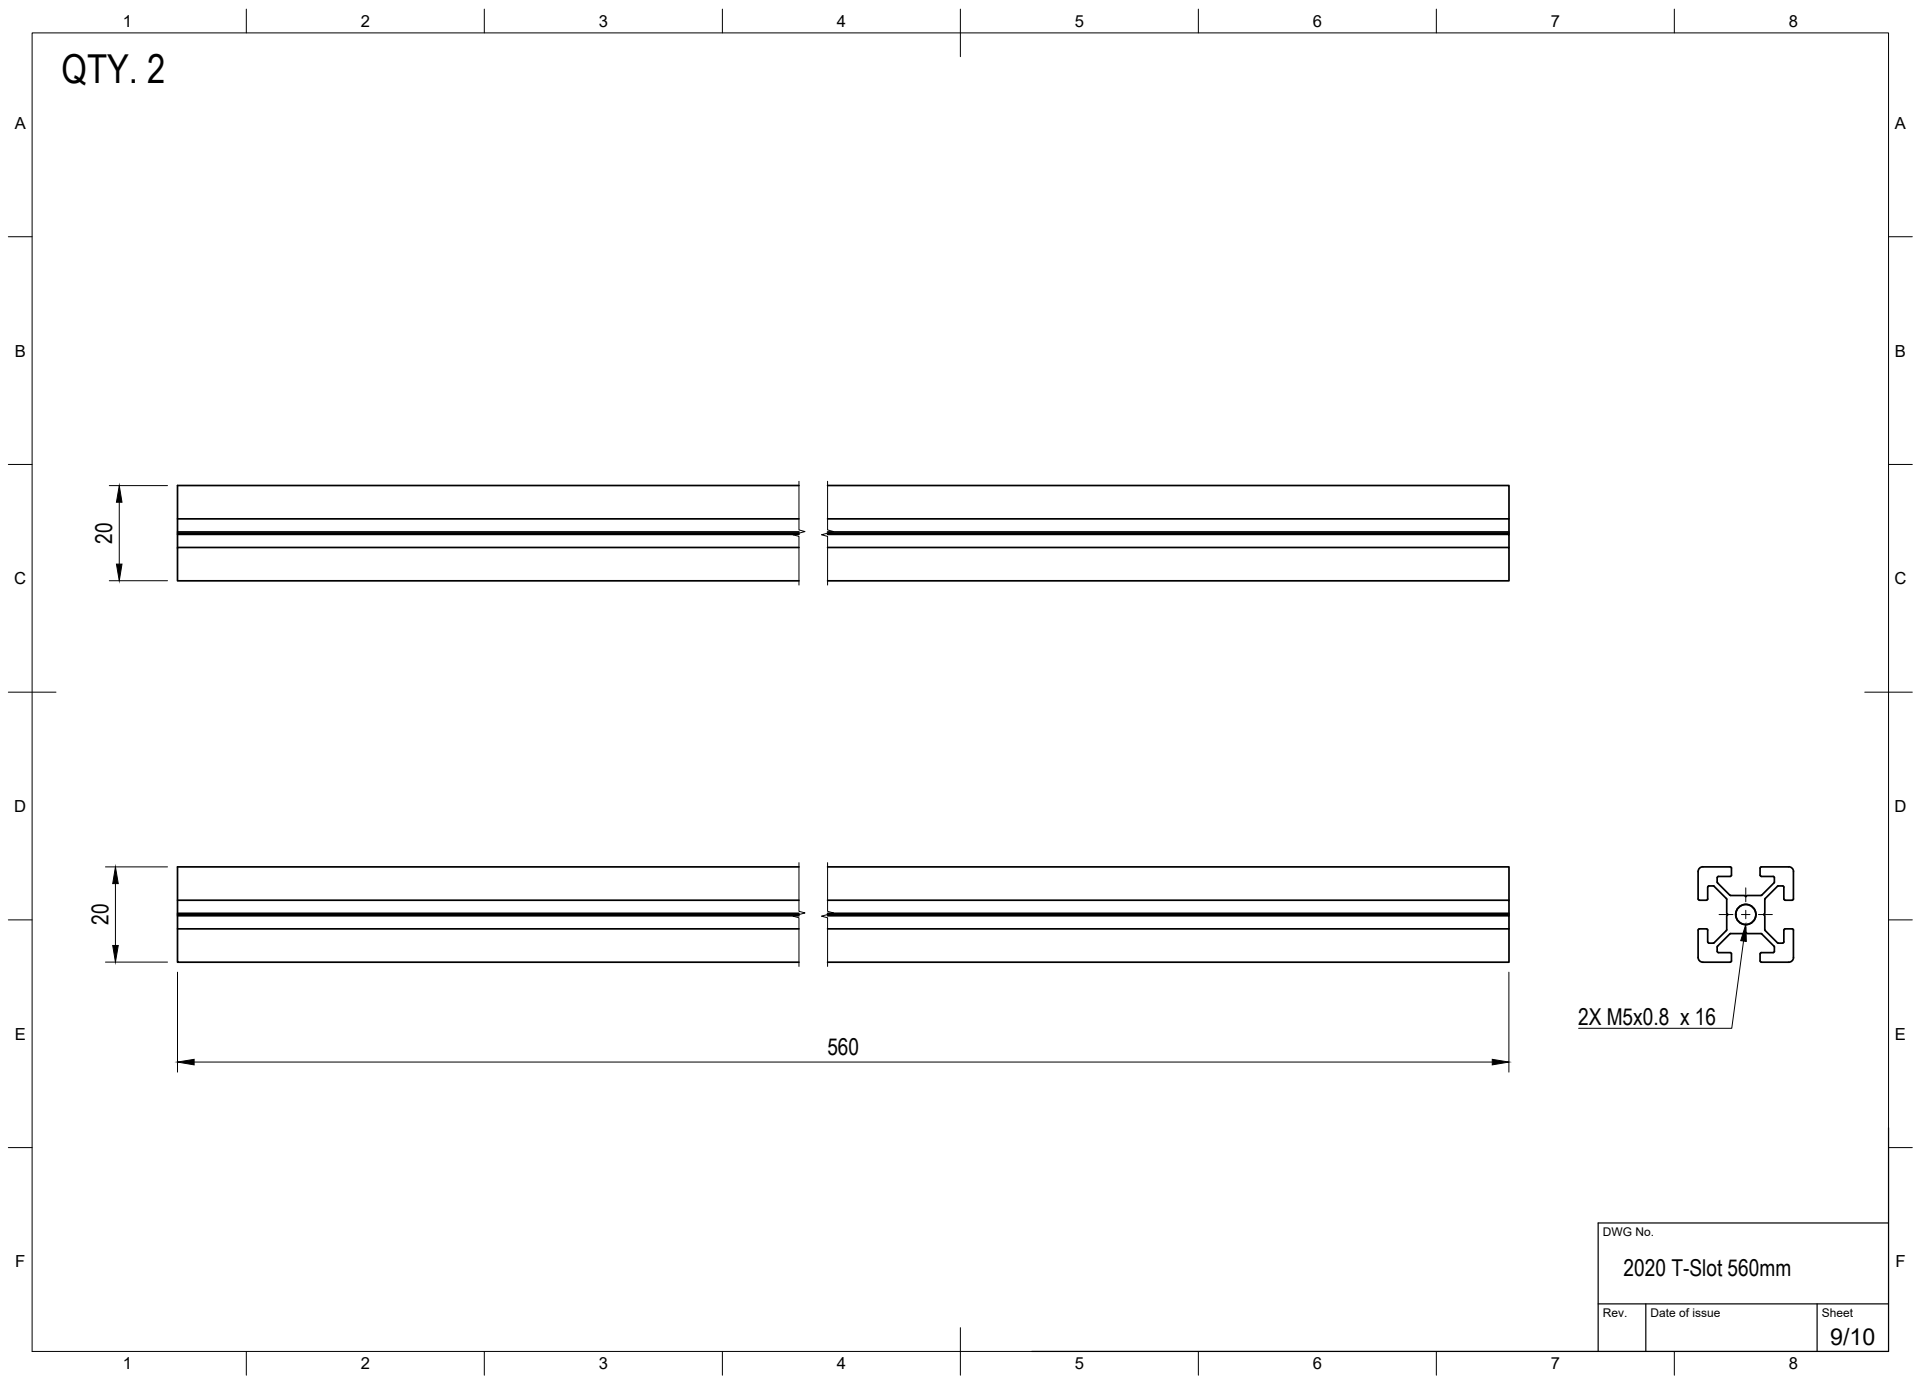
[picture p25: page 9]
DWG No. 2020 T-Slot 560mm

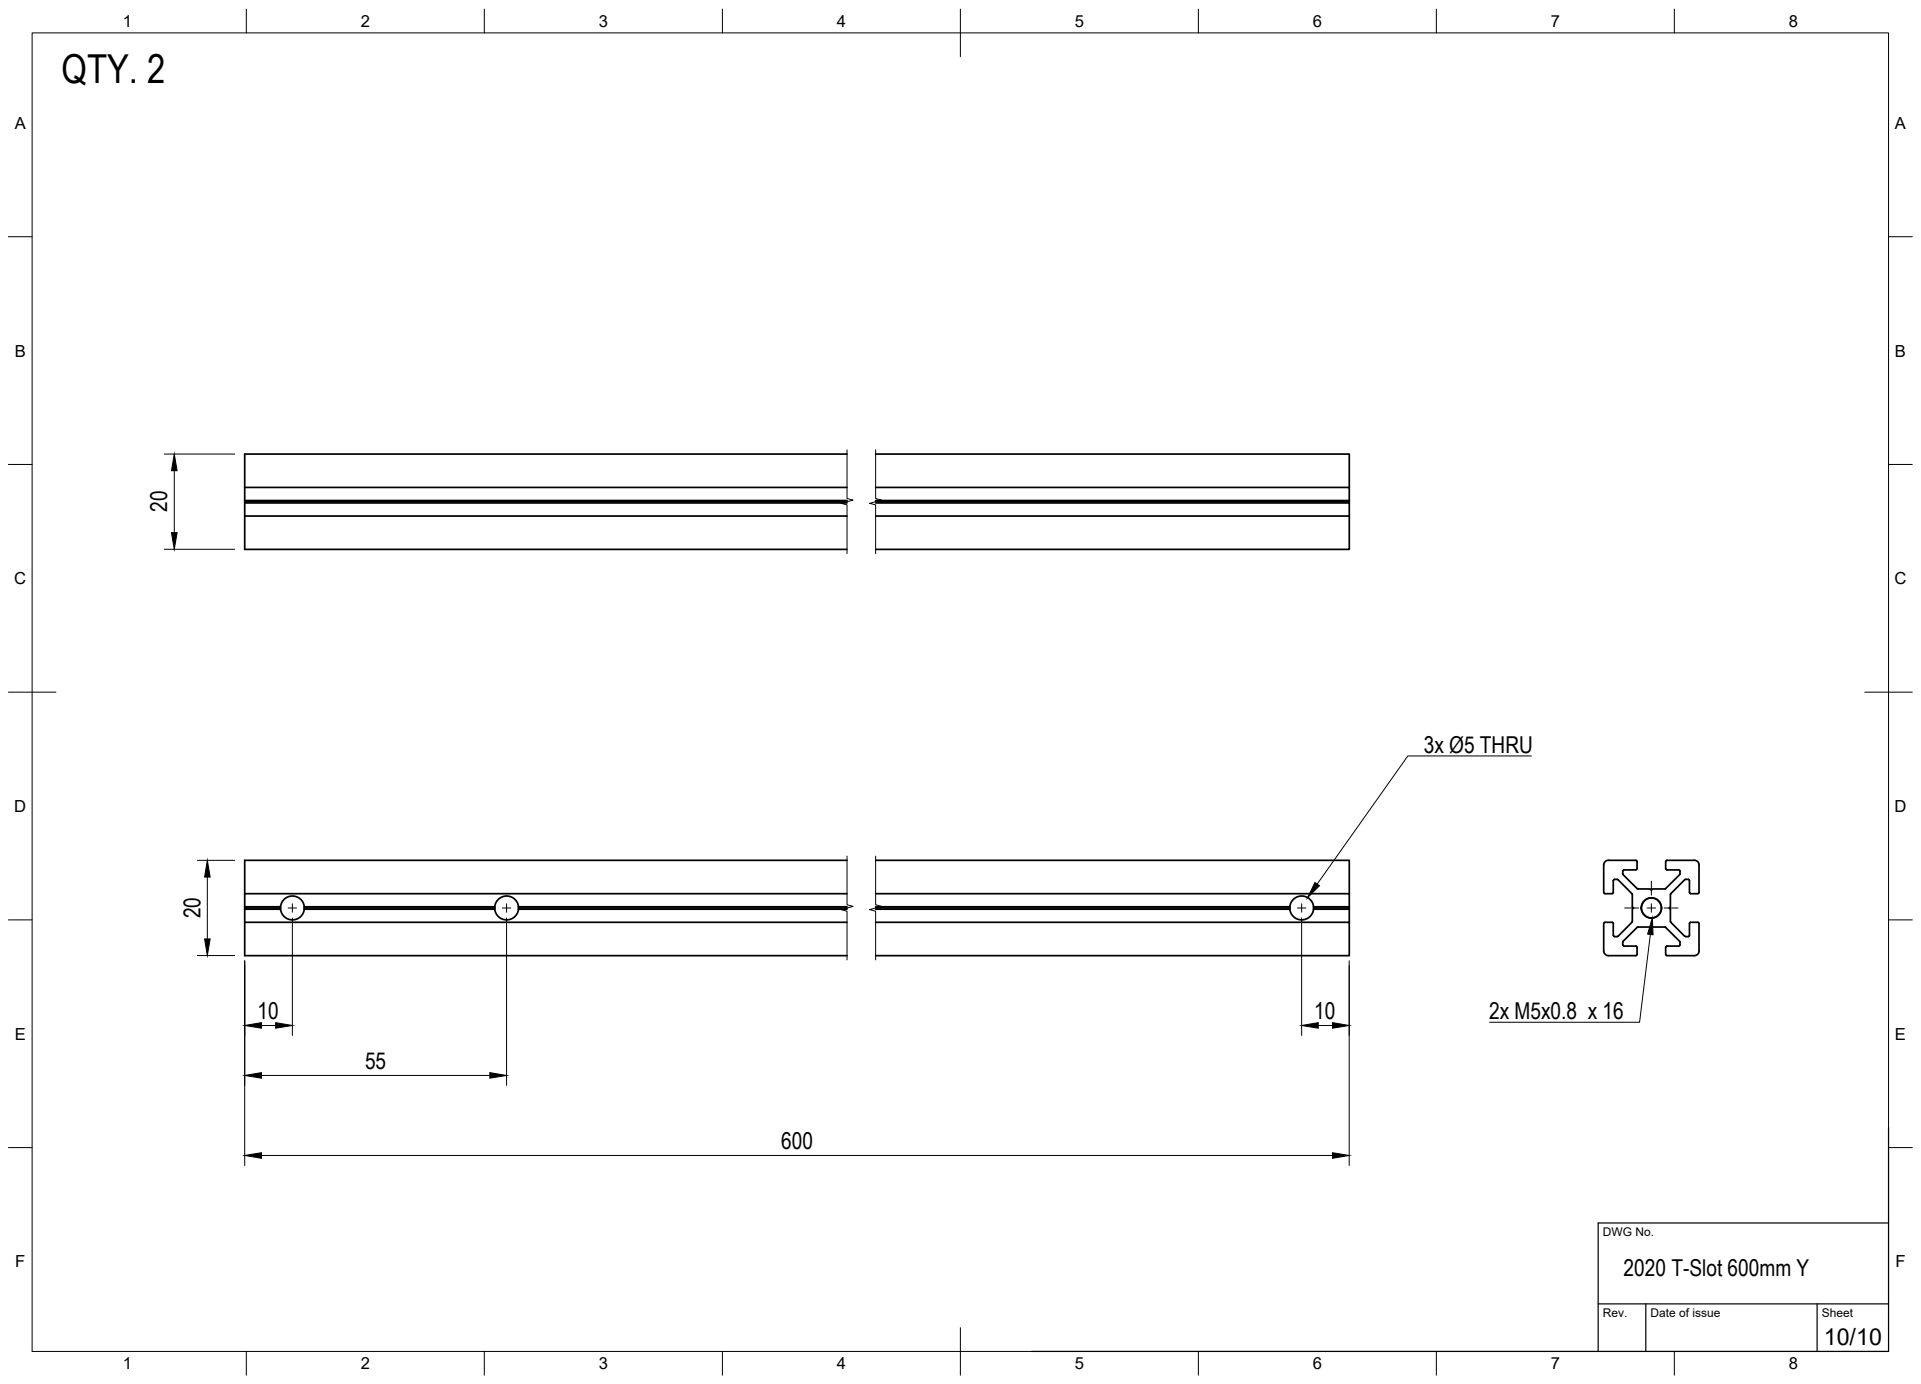
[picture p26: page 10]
DWG No. 2020 T-Slot 600mm Y; 3x Ø5 THRU

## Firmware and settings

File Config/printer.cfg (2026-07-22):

# This file contains common pin mappings for the BigTreeTech Octopus and Octopus Pro boards. 
# To use this config, start by identifying the micro-controller on the board - it may be an STM32F446, STM32F429, or an STM32H723.  
#Select the appropriate micro-controller in "make menuconfig" and select "Enable low-level configuration options". For
# For STM32H723 boards use a "128KiB bootloader" and a "25Mhz crystal".
# See docs/Config_Reference.md for a description of parameters.
[include macros.cfg]
[include KAMP_Settings.cfg]
[display_status]
[exclude_object]
[skew_correction]
[axis_twist_compensation]

[virtual_sdcard]
path: /home/pi3max/printer_data/gcodes

[pause_resume]
recover_velocity: 350

[idle_timeout]
timeout = 10800 #in seconds = 3Hr.

[gcode_arcs]
resolution: 0.05

[respond]
default_type: echo

[printer]
kinematics: corexy
max_velocity: 600
max_accel: 20000
minimum_cruise_ratio: 0.5
max_z_accel: 100
square_corner_velocity: 10.0

[mcu]
serial: /dev/serial/by-id/usb-Klipper_stm32h723xx_3D0011001751313431393536-if00
# canbus_uuid= 
# CAN bus is also available on this board
[temperature_sensor raspberry_pi]
sensor_type: temperature_host
min_temp: 10
max_temp: 100
[mcu EBBCan]
canbus_uuid= 1a248188cc87

[mcu cartographer]        
serial: /dev/serial/by-id/usb-Cartographer_614e_2C000B000F43304146393320-if00           
#backlash_comp: 0.00314
restart_method: command
#mesh_runs: 2

[cartographer]
mcu: cartographer
x_offset: 0
y_offset: 21
verbose: no 

[bed_mesh]
zero_reference_position: 198.50, 179.00
speed: 200
horizontal_move_z: 12
mesh_min: 20, 21
mesh_max: 359, 345
probe_count: 24, 24
algorithm: bicubic
bicubic_tension: 0.42

[z_tilt]
z_positions: 
  -40, -50 #stepper_z Mini Tank
  417, -50 #stepper_z1 Mini Tank
  187.5, 421 #stepper_z2 Mini Tank
points:
  50,23           # ซ้ายหน้า (BL)
  331,23          # ขวาหน้า (BR)
  190,300         # ด้านหลัง (Rear)
speed: 350
horizontal_move_z: 15
retries: 10
retry_tolerance: 0.008

[adxl345]
cs_pin: EBBCan: PB12
spi_software_sclk_pin: EBBCan: PB10
spi_software_mosi_pin: EBBCan: PB11
spi_software_miso_pin: EBBCan: PB2
axes_map: x,y,z

[shaketune]
result_folder: ~/printer_data/config/ShakeTune_results
number_of_results_to_keep: 10
keep_raw_data: False
show_macros_in_webui: True
timeout: 600
measurements_chunk_size: 2
max_freq: 200
dpi: 300

[resonance_tester]
accel_chip: adxl345
probe_points: 180,165,10

[safe_z_home] 
home_xy_position: 198.5,179.00
z_hop: 2
z_hop_speed: 20
speed: 150

[force_move]
enable_force_move: True

#==================================================
# Driver0
[stepper_x] #LDO-42STH48-2804AH-R 2.8A 
step_pin: PF13
dir_pin: !PF12
enable_pin: !PF14
microsteps: 16
rotation_distance: 40
full_steps_per_rotation: 200
endstop_pin: EBBCan:PB6
position_endstop: 0
position_max: 398
homing_speed: 150
[tmc5160 stepper_x]
cs_pin: PC4
spi_bus: spi1
run_current: 1.9700
interpolate: true
stealthchop_threshold: 0
#interpolate: true
#tealthchop_threshold: 999999


# Driver1
[stepper_y] #LDO-42STH48-2804AH-R 2.8A 
step_pin: PG0
dir_pin: !PG1
enable_pin: !PF15
microsteps: 16
rotation_distance: 40
full_steps_per_rotation: 200
endstop_pin: PG6
position_endstop: 0
position_max: 390
homing_speed: 150
[tmc5160 stepper_y]
cs_pin: PD11
spi_bus: spi1
run_current: 1.9700
interpolate: true
stealthchop_threshold: 0
#interpolate: true
#stealthchop_threshold: 999999

# Driver5 
[stepper_z]  #42DND887C-20D18 1.7A 0.55 N.m
step_pin: PC13
dir_pin: PF0
enable_pin: !PF1
microsteps: 16
rotation_distance: 8
endstop_pin: probe:z_virtual_endstop
homing_retract_dist: 0
position_min: -30.0
position_max: 375
homing_speed: 10
[tmc2209 stepper_z]
uart_pin: PE4
diag_pin: PG10
run_current: 1.45
hold_current: 1.00
interpolate: true
stealthchop_threshold: 0

# Driver6
[stepper_z1] #42DND887C-20D18 1.7A 0.55 N.m
step_pin: PE2
dir_pin: PE3
enable_pin: !PD4
microsteps: 16
rotation_distance: 8
endstop_pin: probe:z_virtual_endstop
[tmc2209 stepper_z1]
uart_pin: PE1
diag_pin: PG11
run_current: 1.45
hold_current: 1.00
interpolate: true
stealthchop_threshold: 0


# Driver7

[stepper_z2] #42DND887C-20D18 1.7A 0.55 N.m
step_pin: PE6
dir_pin: PA14
enable_pin: !PE0
microsteps: 16
rotation_distance: 8
endstop_pin: probe:z_virtual_endstop
[tmc2209 stepper_z2]
uart_pin: PD3
diag_pin: PG12
run_current: 1.45
hold_current: 1.00
interpolate: true
stealthchop_threshold: 0

#==================================================

# Driver3
# The Octopus only has 4 heater outputs which leaves an extra stepper
# This can be used for a second Z stepper, dual_carriage, extruder co-stepper,
# or other accesory such as an MMU
#[stepper_]
#step_pin: PG4
#dir_pin: PC1
#enable_pin: PA2
#endstop_pin: PG11
#...

# Driver5(EBB36)
[extruder] #10Teeth LDO 36STH20-1004AHG(XH)
max_extrude_only_distance: 1000.0
max_extrude_cross_section: 500
max_extrude_only_velocity: 200
max_extrude_only_accel: 10000
step_pin: EBBCan: PD0
dir_pin: !EBBCan: PD1
enable_pin: !EBBCan: PD2
#step_pin: PF9
#dir_pin: PF10
#enable_pin: !PG2
microsteps: 16
rotation_distance: 22.5888
gear_ratio: 50:10
nozzle_diameter: 0.400
filament_diameter: 1.750
#heater_pin: PA0 # HE0
heater_pin: EBBCan: PB13
#sensor_pin:  PF4 # T0
#sensor_type: EPCOS 100K B57560G104F
sensor_type: MAX31865
sensor_pin: EBBCan: PA4
spi_bus: spi1
rtd_nominal_r: 1000
rtd_reference_r: 4300
rtd_num_of_wires: 2
#control: pid
#pid_Kp: 22.2
#pid_Ki: 1.08
#pid_Kd: 114
min_temp: -10
max_temp: 420
min_extrude_temp: -10
[tmc2209 extruder]
uart_pin: EBBCan: PA15
run_current: 0.8
hold_current: 0.6      
stealthchop_threshold: 0
interpolate: False
sense_resistor: 0.110
#==================================================

# Driver5
#[extruder1]
#step_pin: PC13
#dir_pin: PF0
#enable_pin: !PF1
#heater_pin: PA3 # HE1
#sensor_pin: PF5 # T1
#...

# Driver6
#[extruder2]
#step_pin: PE2
#dir_pin: PE3
#enable_pin: !PD4
#heater_pin: PB0 # HE2
#sensor_pin: PF6 # T2
#...

# Driver7
#[extruder3]
#step_pin: PE6
#dir_pin: PA14
#enable_pin: !PE0
#heater_pin: PB11 # HE3
#sensor_pin: PF7 # T3
#...

[filament_switch_sensor LLL_Buffer]
pause_on_runout: False
switch_pin: ^!PG12
event_delay: 1.5
pause_delay: 0.25
runout_gcode:
  RESPOND TYPE=echo MSG="LLL Filament Out"
insert_gcode:
  RESPOND TYPE=echo MSG="LLL Filament Inserted"

[filament_switch_sensor mdm_switch_sensor]
switch_pin: ^PG13
pause_on_runout: True
runout_gcode:
    PAUSE
    RESPOND TYPE=echo MSG="Filament out"
event_delay: 1.0
pause_delay: 0.5

# [filament_motion_sensor mdm_motion_sensor]
# switch_pin: PG14
# detection_length: 3.5
# extruder: extruder
# runout_gcode:
#   PAUSE
#   RESPOND TYPE=echo MSG="Filament jam"
# event_delay: 3.0
# pause_delay: 1.0

#[filament_switch_sensor material_1]
#switch_pin: PG13
#[filament_switch_sensor material_2]
#switch_pin: PG14
#[filament_switch_sensor material_3]
#switch_pin: PG15

#==================================================
[heater_bed]
heater_pin: PA1
sensor_pin: PF3 # TB
sensor_type: EPCOS 100K B57560G104F
#control: pid
#pid_Kp: 63.133
#pid_Ki: 3.263
#pid_Kd: 305.405
min_temp: 0
max_temp: 150

[output_pin Extruder_fan] #EBB Cooling 4040 Fan
pin: EBBCan: PA0
pwm: True
value: 1.0
shutdown_value: 0
[fan]
pin: EBBCan: PA1

[temperature_sensor cartographer]
sensor_type: temperature_mcu
sensor_mcu: cartographer
min_temp: 0
max_temp: 105

[temperature_sensor EBB36]
sensor_type: temperature_mcu
sensor_mcu: EBBCan
min_temp: 0
max_temp: 100

#TB-PF3 T0-PF4 T1-PF5 T2-PF6 T3-PF7

[temperature_sensor Chamber_REAR]
sensor_type: EPCOS 100K B57560G104F
sensor_pin: PF4
[temperature_sensor Chamber_RIGHT]
sensor_type: EPCOS 100K B57560G104F
sensor_pin: PF5
[temperature_sensor Chamber_LEFT]
sensor_type: EPCOS 100K B57560G104F
sensor_pin:PF6

[temperature_sensor Chamber_average]
sensor_type: temperature_combined
sensor_list: temperature_sensor Chamber_REAR, temperature_sensor Chamber_RIGHT, temperature_sensor Chamber_LEFT
combination_method: mean
maximum_deviation: 50.0
min_temp: 0
max_temp: 80

[temperature_sensor Electronics]
sensor_type: EPCOS 100K B57560G104F
sensor_pin:PF7
########################################

[output_pin MBfan1]
pin: PD13
value: 1.0
shutdown_value: 1.0

[output_pin MBfan2]
pin: PD14
value: 1.0
shutdown_value: 1.0

########################################

[output_pin LED_Left]
pin: PE5
value: 1          # ตั้งค่าเริ่มต้นเป็น 1 (เปิด)
shutdown_value: 0 # ตั้งค่าเมื่อ shutdown เป็น 0 (ปิด)

[output_pin LED_Right]
pin: PA8
value: 1          # ตั้งค่าเริ่มต้นเป็น 1 (เปิด)
shutdown_value: 0 # ตั้งค่าเมื่อ shutdown เป็น 0 (ปิด)

#[output_pin Circulation_Fan]
#pin: PD12
#pwm: True
#value: 0.6
#shutdown_value: 0

[neopixel hotend_rgb]
pin: EBBCan:PD3
chain_count: 1
color_order: GRBW
initial_RED: 1.0
initial_GREEN: 1.0
initial_BLUE: 1.0
initial_WHITE: 1.0

[firmware_retraction]
retract_length: 0
retract_speed: 20
unretract_extra_length: 0
unretract_speed: 10
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

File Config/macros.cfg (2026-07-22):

[gcode_macro PRINT_START]
gcode:
  {% set target_bed = params.BED_TEMP|default(50)|int %}
  {% set target_extruder = params.EXTRUDER_TEMP|default(240)|int %}
  {% set x_wait = printer.toolhead.axis_maximum.x|float / 2 %}
  {% set y_wait = printer.toolhead.axis_maximum.y|float / 2 %}
  M140 S{target_bed}
  M104 S140

  M190 S{target_bed}

  {% if target_bed >= 100 and target_bed <= 120 %}
    {action_respond_info("Bed temp is between 100-120C. Soaking for 5 minutes...")}
    G4 P300000                ; Soak 5 นาที สำหรับ ABS/ASA
  {% elif target_bed >= 70 and target_bed <= 90 %}
    {action_respond_info("Bed temp is between 70-90C. Soaking for 2 minutes...")}
    G4 P120000                ; Soak 2 นาที สำหรับ PETG
  {% endif %}
  G28
  _Z_TILT_MAYBE
  BED_MESH_CLEAR
  BED_MESH_CALIBRATE

  SMART_PARK
  M109 S{target_extruder}
  TEMPERATURE_WAIT SENSOR=extruder MINIMUM={target_extruder-2}

  LINE_PURGE             
  {action_respond_info("Printer goes brr")}

[gcode_macro PRINT_END]
gcode:
    {% set max_x = printer.configfile.config["stepper_x"]["position_max"]|float %}
    {% set max_y = printer.configfile.config["stepper_y"]["position_max"]|float %}
    {% set max_z = printer.configfile.config["stepper_z"]["position_max"]|float %}
    
    {% if printer.toolhead.position.x < (max_x - 15) %}
        {% set x_safe = 10.0 %}
    {% else %}
        {% set x_safe = -10.0 %}
    {% endif %}

    {% if printer.toolhead.position.y < (max_y - 15) %}
        {% set y_safe = 10.0 %}
    {% else %}
        {% set y_safe = -10.0 %}
    {% endif %}

    {% if printer.toolhead.position.z < (max_z - 2) %}
        {% set z_safe = 50.0 %}
    {% else %}
        {% set z_safe = max_z - printer.toolhead.position.z %}
    {% endif %}

    M400                             ; wait for buffer to clear
    G92 E0                           ; zero the extruder
    G1 E-10.0 F3600                   ; retract 10mm
    G91                              ; relative positioning
    G0 Z{z_safe} + Z10 F3600         ; move nozzle up
    G0 X{x_safe} Y{y_safe} F20000    ; move nozzle to remove stringing
    M104 S0                          ; turn off hotend
    M140 S0                          ; turn off bed
    M106 S0                          ; turn off fan
    G90                              ; absolute positioning
    G0 X395.5 Y22 F18000   ; park nozzle at Front
    G0 X395.5 Y14 F6000    ; park nozzle at Parker
    G0 Z360 F1200
    M117 Finished!

[gcode_macro PAUSE]
description: Pause the actual running print
rename_existing: PAUSE_BASE
variable_extrude: 1.0
variable_saved_extruder_temp: 0
gcode:
    {% set x_inter = 393 %}
    {% set y_inter = 22 %}
    {% set x_park = 395.5 %}
    {% set y_park = 14 %}
    {% set z = params.Z|default(10)|float %}
    {% set e = params.E|default(1) %}
    {% set max_z = printer.toolhead.axis_maximum.z|float %}
    {% set act_z = printer.toolhead.position.z|float %}
    {% set lift_z = z|abs %}
    {% if act_z < (max_z - lift_z) %}
        {% set z_safe = lift_z %}
    {% else %}
        {% set z_safe = max_z - act_z %}
    {% endif %}
    
    SET_GCODE_VARIABLE MACRO=PAUSE VARIABLE=saved_extruder_temp VALUE={printer.extruder.target}
    SAVE_GCODE_STATE NAME=PAUSE_state
    PAUSE_BASE
    G91
    {% if printer.extruder.can_extrude|lower == 'true' %}
        G1 E-{e} F2100
    {% else %}
        {action_respond_info("Extruder not hot enough")}
    {% endif %}
    
    {% if "xyz" in printer.toolhead.homed_axes %}    
        G1 Z{z_safe} F600
        G90
        G1 X{x_inter} Y{y_inter} F6000
        G1 X{x_park} Y{y_park} F6000
    {% else %}
        {action_respond_info("Printer not homed")}
    {% endif %}
    M104 S150

[gcode_macro RESUME]
description: Resume the actual running print
rename_existing: RESUME_BASE
gcode:
    {% set e = params.E|default(3) %}
    {% set x_inter = 393 %}
    {% set y_inter = 22 %}
    
    {% if 'VELOCITY' in params|upper %}
        {% set get_params = ('VELOCITY=' + params.VELOCITY)  %}
    {% else %}
        {% set get_params = "" %}
    {% endif %}
    
    {% set saved_temp = printer["gcode_macro PAUSE"].saved_extruder_temp %}
    {% if saved_temp > 0 %}
        M109 S{saved_temp}
    {% endif %}
    
    {% if printer.extruder.can_extrude|lower == 'true' %}
        G91
        G1 E{e} F2100
        G90
    {% else %}
        {action_respond_info("Extruder not hot enough")}
    {% endif %}
    G90
    G1 X{x_inter} Y{y_inter} F6000
    RESTORE_GCODE_STATE NAME=PAUSE_state MOVE=1
    RESUME_BASE {get_params}

[gcode_macro M18]
rename_existing: M1800
gcode:
  M1800 {rawparams}
  SET_GCODE_VARIABLE MACRO=Z_TILT_ADJUST VARIABLE=adjusted VALUE=0

[gcode_macro M84]
rename_existing: M8400
gcode:
  M8400 {rawparams}
  SET_GCODE_VARIABLE MACRO=Z_TILT_ADJUST VARIABLE=adjusted VALUE=0

[gcode_macro G29]
gcode:
    M140 S110
    M190 S110
    G28
    #Z_TILT_ADJUST
    BED_MESH_CALIBRATE profile=mesh
    #BED_MESH_PROFILE SAVE=mesh 
    SAVE_CONFIG

[gcode_macro LOAD_MATERIAL]
gcode:
  {% if printer.extruder.temperature < 240 %}
  M104 S240
  {% endif %}
  NOZZLE_WIPE
  G1 X390 Y65 F12000
  G1 X390 Y53 F12000
  G91
  G1 E140 F180
  
[gcode_macro LOAD_FILAMENT]
gcode:
  {% set load_temp = params.T|default(250)|int %}
  # SPEED เป็น mm/min แต่ล็อกไม่ให้เกิน 600 (10 mm/s)
  {% set req_speed = params.SPEED|default(600)|int %}
  {% set max_speed = 600 %}
  {% set speed = req_speed if req_speed <= max_speed else max_speed %}
  SAVE_GCODE_STATE NAME=LOAD_STATE
  # รอหัวถึง temp ก่อน
  {% if printer.extruder.temperature < load_temp - 5 %}
    M109 S{load_temp}
  {% endif %}
  G91
  G92 E0
  # โหลดเส้น 135 mm @ speed ≤ 10 mm/s
  G1 E135 F{speed}
  RESTORE_GCODE_STATE NAME=LOAD_STATE

[gcode_macro QUIT_MATERIAL]
gcode:
  SAVE_GCODE_STATE NAME=myMoveState
  M109 S240
  M83                   # Put the extruder into relative mode
  G92 E0.0              # Reset the extruder so that it thinks it is at position zero
  G1 E-125 F350          # Move the extruder forward 120mm at a speed of 350mm/minute
  G92 E0.0              # Reset the extruder again
  M82                   # Put the extruder back into absolute mode.
  RESTORE_GCODE_STATE NAME=myMoveState

[gcode_macro UNLOAD_FILAMENT]
description: "Unload filament with a configurable two-stage retraction"

variable_default_temp: 240          # อุณหภูมิเริ่มต้น (สำหรับ PETG/ABS/ASA)
variable_prime_dist: 5              # ระยะดันเส้นเพื่อลดแรงดัน (mm)
variable_fast_retract_dist: 60      # ระยะดึงเร็วเพื่อเคลียร์ Hotend (mm)
variable_slow_retract_dist: 55      # ระยะดึงช้าเพื่อเคลียร์ชุดขับ (mm)
variable_fast_retract_speed: 3000   # ความเร็วในการดึงเร็ว (mm/min -> 50mm/s)
variable_slow_retract_speed: 1500   # ความเร็วในการดึงช้า (mm/min -> 25mm/s)
variable_turn_off_heater: True      # ปิด Heater หลังทำงานเสร็จ (True/False)

gcode:
    {% set TEMP = params.T|default(default_temp)|float %}
    SAVE_GCODE_STATE NAME=UNLOAD_FILAMENT_STATE
    M117 Heating for Unload...
    {% if printer.extruder.temperature < TEMP %}
        M109 S{TEMP}      # ทำความร้อนเมื่ออุณหภูมิต่ำกว่าที่กำหนดเท่านั้น
    {% endif %}
    G91
    M117 Unloading...         # เริ่มกระบวนการดึงเส้นแบบสองจังหวะ
    G1 E{prime_dist} F300
    G1 E-{fast_retract_dist} F{fast_retract_speed}
    G1 E-{slow_retract_dist} F{slow_retract_speed}
    {% if turn_off_heater %}
        M104 S0 # ปิด Heater
    {% endif %}
    G90
    RESTORE_GCODE_STATE NAME=UNLOAD_FILAMENT_STATE
    M117 Unload Complete!

[gcode_macro Filament_Change]
gcode:
    # Save the G-code state
    SAVE_GCODE_STATE NAME=filament_change

    # Move the extruder to the side
    G1 X5 Y225 F4000
    
    # Unload the filament
    {% if printer.extruder.can_reverse %} 
        G91
        G1 E-10 F100
        G92 E0
        G90
    {% else %}
        M117 Extruder cannot reverse
    {% endif %}
    # Wait for user interaction to confirm new roll of filament
    M117 Please insert new filament and confirm
    # Prime the nozzle with new filament
    G91
    G1 E10 F100
    G92 E0
    G1 E5 F200
    G90
    # Restore the G-code state
    RESTORE_GCODE_STATE NAME=filament_change

[gcode_macro CANCEL_PRINT]
rename_existing: BASE_CANCEL_PRINT
gcode:
    {% set max_x = printer.configfile.config["stepper_x"]["position_max"]|float %}
    {% set max_y = printer.configfile.config["stepper_y"]["position_max"]|float %}
    {% set max_z = printer.configfile.config["stepper_z"]["position_max"]|float %}

    G91 # Set to incremental mode
    G0 Z10 F600 # raise extruder
    G90 # Set back to absolute mode
    TURN_OFF_HEATERS
    NOZZLE_WIPE
    G0 X390 Y51 F18000 # Clear Print
    CLEAR_PAUSE
    SDCARD_RESET_FILE
    BASE_CANCEL_PRINT

[gcode_macro PID_HOTEND]
#variable_target_temp: 240
gcode:
    {% set TARGET_TEMP_HOTEND = params.TARGET_TEMP_HOTEND|default(target_temp) %}
    M104 S{TARGET_TEMP_HOTEND}
    PID_CALIBRATE HEATER=extruder TARGET={TARGET_TEMP_HOTEND}
    SAVE_CONFIG
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

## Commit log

2026-07-22 chore(git): add .gitignore for OS files, IDE configs, and Klipper backups
2026-07-22 refactor(stl): move loose toolhead STL files into ToolsHead folder
    [beacon_bottom_trihorns.stl, drive_orbiter_2_0.stl, rear_inlet_single_5015.stl]
2026-07-22 feat(config): add production Klipper configuration files and macros
    [AI.cfg, Adaptive_Meshing.cfg, KAMP_Settings.cfg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]
2026-07-22 docs(bom): add comprehensive Bill of Materials specification
2026-07-22 docs(readme): rewrite README and update assembly guide with system diagrams and Klipper workflow

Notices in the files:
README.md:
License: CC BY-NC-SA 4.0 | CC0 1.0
